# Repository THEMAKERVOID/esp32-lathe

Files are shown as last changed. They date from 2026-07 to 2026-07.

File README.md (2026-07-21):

# TheMakerVoid ELS — ESP32-S3 Electronic Lead Screw



An open-source **Electronic Lead Screw (ELS)** controller for manual lathes, built around the ESP32-S3 and a 320×240 ILI9341 TFT touchscreen. Synchronizes a servo/stepper motor with spindle rotation to automate feed and thread cutting operations.

> 🍺 **This project is free and open source.** If it's useful to you, consider [buying me a beer](https://buymeacoffee.com/themakervoid) — it helps keep the open-source hardware coming. Thank you!

---

## Features

- **4 operating modes** — Feed, Thread, Divider, and Configuration
- **Metric & Imperial (UTS) threads** — 16 metric pitches (0.20–4.00 mm) and 21 imperial pitches (8–56 TPI), selectable from the Thread Unit Switch screen
- **5 feed rates** — 0.07, 0.10, 0.13, 0.18, 0.25 mm/rev
- **Angular divider** — real-time angle readout from encoder
- **Dual input** — XPT2046 resistive touchscreen (debounced) and 4 physical buttons
- **Dark mode UI** — Figma-designed dark interface with Orbitron bitmap fonts
- **EEPROM persistence** — motor direction, lead screw pitch, and dark mode saved across power cycles
- **Dual-core architecture** — UI on Core0, servo synchronization on Core1 (FreeRTOS)
- **Bresenham pulse algorithm** — precise stepper pulse generation without floating-point drift

---

## Hardware

| Component | Details |
|---|---|
| Microcontroller | ESP32-S3 DevKit C-1 |
| Display | ILI9341 TFT 320×240, landscape |
| Encoder | Quadrature rotary encoder, 1440 pulses/rev |
| Servo/Stepper driver | [Lichuan AC servo driver (PUL/DIR interface)](https://s.click.aliexpress.com/e/_c3kWTQaX) |
| Touchscreen | XPT2046 resistive controller (on the ILI9341 module) |
| Input | XPT2046 touchscreen + 4 physical buttons: UP, DOWN, SELECT, BACK |

### Where to Buy

| Component | Link |
| --- | --- |
| AC Servo motor + driver | [AliExpress](https://s.click.aliexpress.com/e/_c3kWTQaX) |

**Recommended model: 1,000 W** — select the "1KW 4Nm 17b incremt" option (model **LCMT-10SLC17NB-80M04025B**): 4 Nm torque, 2500 RPM, 80 mm mounting flange (same specs as the unit used in this project).

*Affiliate link — as an AliExpress affiliate I may earn a commission at no extra cost to you.*

### Pin Map

| Function | GPIO |
|---|---|
| TFT CS / DC / RST | 10 / 11 / 12 |
| TFT SCK / MOSI / MISO | 15 / 13 / 14 |
| Touch CS / IRQ | 16 / 255 (IRQ unused) |
| Encoder A / B | 20 / 21 |
| Stepper PUL / DIR | 8 / 9 |
| BTN UP / DOWN / SELECT / BACK | 4 / 5 / 6 / 7 |
| Brake (reserved) | 3 |
| Encoder Z index (reserved) | 2 |

---

## UI Screens

| Screen | Description |
|---|---|
| Splash | Logo + boot animation |
| Main Menu | Mode selection + live RPM |
| Feed Select | Feed rate selection grid |
| Feed Mode | Active feed display + live RPM |
| Thread Unit Switch | Select Metric (mm) or Imperial (TPI) |
| Thread Select | Paginated pitch grid |
| Thread Mode | Active thread display + live RPM |
| Divider | Real-time angular position |
| Menu Overlay | Navigation hub |
| Config — Direction | CW / CCW motor direction |
| Config — Lead Screw Pitch | 1–10 mm digit selector |
| Interface | Dark mode toggle |
| Info | Firmware version and credits |

---

## Software Setup

### Requirements

- [Arduino IDE 2.x](https://www.arduino.cc/en/software)
- ESP32-S3 board package (via Boards Manager: `esp32` by Espressif)
- Libraries (via Library Manager):
  - Adafruit GFX Library
  - Adafruit ILI9341
  - XPT2046_Touchscreen
  - EEPROM (included with ESP32 core)

### Build & Flash

1. Clone or download this repository
2. Open `esp32-lathe/esp32-lathe.ino` in Arduino IDE 2.x
3. Select board: **ESP32S3 Dev Module**
4. Flash partition scheme: **Huge APP (3MB No OTA/1MB SPIFFS)** (recommended for PROGMEM bitmaps)
5. Upload

> **Note:** VS Code IntelliSense may show false errors for ESP32 headers. Arduino IDE 2.x compiles correctly.

---

## Project Structure

```
esp32-lathe/
├── esp32-lathe.ino       # Main sketch
├── bitmaps/              # PROGMEM RGB565 bitmap headers
│   ├── logo_splash.h
│   ├── bg_main.h
│   ├── btn_menu.h
│   ├── btn_back.h
│   ├── btn_ok.h
│   ├── btn_reload.h
│   ├── btn_stepper.h
│   ├── solid.h
│   └── btn_slider.h
├── Fonts/                # Orbitron & Montserrat bitmap font headers
│   ├── Orbitron_Medium8pt7b.h
│   ├── Orbitron_Medium12pt7b.h
│   ├── Orbitron_Medium18pt7b.h
│   ├── Orbitron_Medium24pt7b.h
│   └── Montserrat_Light6pt7b.h
└── Resources/            # Manuals, BOM, and 3D models (see Documentation)
    ├── User_Manual.pdf        # User manual (English)
    ├── Manual_Usuario.pdf     # User manual (Spanish)
    ├── ELS_Componentes.pdf    # Bill of materials / component list
    ├── Schematic.pdf          # Circuit schematic
    └── Components/            # 3D models of the mechanical parts (STEP / STL)
        ├── Base.STEP
        ├── Axis.STEP
        ├── Support.STEP
        ├── Encoder support.STEP
        ├── Main Pulley 50 Theet HTD5.STEP
        ├── Lathe Pulley 50 theet.STEP
        └── Frontal Caja Elecronica.STL
```

---

## How It Works

The encoder mounted on the lathe spindle generates quadrature pulses (1440 p/rev). Core1 runs a high-priority FreeRTOS task that reads the encoder count and computes stepper pulses using a **Bresenham integer accumulator**:

```
accumulator += |encoderDelta| × (desiredPitch × 100)
pulsesToSend  = accumulator / (leadScrewPitch × 100)
accumulator  %= (leadScrewPitch × 100)
```

This produces exact pulse ratios without floating-point error accumulation, enabling accurate thread cutting and feed synchronization.

---

## Documentation

Full user manuals and the component list are available in the [`esp32-lathe/Resources/`](esp32-lathe/Resources/) folder:

| Document | Language | Description |
|---|---|---|
| [User_Manual.pdf](esp32-lathe/Resources/User_Manual.pdf) | English | Complete user manual — operation, modes, and configuration |
| [Manual_Usuario.pdf](esp32-lathe/Resources/Manual_Usuario.pdf) | Español | Manual de usuario completo — funcionamiento, modos y configuración |
| [ELS_Componentes.pdf](esp32-lathe/Resources/ELS_Componentes.pdf) | Español | Bill of materials with links to the referenced parts / lista de componentes con enlaces a los referidos |
| [Schematic.pdf](esp32-lathe/Resources/Schematic.pdf) | — | Circuit schematic / esquema del circuito |

### 3D Models (mechanical parts)

3D models of the custom mechanical parts are in [`esp32-lathe/Resources/Components/`](esp32-lathe/Resources/Components/). STEP files are neutral CAD format (editable in any CAD tool); the STL is print-ready and previews directly on GitHub.

| Part | Format |
|---|---|
| [Base](esp32-lathe/Resources/Components/Base.STEP) | STEP |
| [Axis](esp32-lathe/Resources/Components/Axis.STEP) | STEP |
| [Support](esp32-lathe/Resources/Components/Support.STEP) | STEP |
| [Encoder support](esp32-lathe/Resources/Components/Encoder%20support.STEP) | STEP |
| [Main Pulley 50T HTD5](esp32-lathe/Resources/Components/Main%20Pulley%2050%20Theet%20HTD5.STEP) | STEP |
| [Lathe Pulley 50T](esp32-lathe/Resources/Components/Lathe%20Pulley%2050%20theet.STEP) | STEP |
| [Electronics box front](esp32-lathe/Resources/Components/Frontal%20Caja%20Elecronica.STL) | STL (3D-printable) |

---

## License

This project is open-source. See [LICENSE](LICENSE) for details.

---

## Credits

**TheMakerVoid** — [www.themakervoid.com](https://www.themakervoid.com)

Contributions, issues, and pull requests are welcome.

If this project helps you, support it with a beer 🍺 → [buymeacoffee.com/themakervoid](https://buymeacoffee.com/themakervoid)

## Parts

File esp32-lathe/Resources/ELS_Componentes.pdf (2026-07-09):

# Lista de Componentes — Proyecto ELS

Total de referencias: 11 · Ordenado alfabéticamente

Componente | Descripción | Cantidad | Enlace
Acoplador flexible de eje (Beam Coupling) | Acoplador de tipo helicoidal en aluminio negro, para transmisión de movimiento entre ejes con compensación de desalineación. | 1 unidad | AliExpress (https://s.click.aliexpress.com/e/_c445kgMx)
Conectores hembra para PCB (Pin Headers 2.54mm) | Tiras de conectores hembra de paso 2.54mm en negro. | 2×22 pines, 1×14 pines, 1×4 pines | AliExpress (https://s.click.aliexpress.com/e/_c41DaZ35)
Correa dentada HTD 5M 535mm | Correa sincrónica cerrada HTD-535-5M, paso 5mm, ancho 10mm. Para transmisión por polea dentada sin deslizamiento. | 1 unidad | AliExpress (https://s.click.aliexpress.com/e/_c3nUDYUb)
Display TFT 2.8" con pantalla táctil (SPI) | Módulo display TFT 2.8 pulgadas con táctil resistivo, interfaz SPI, controlador ILI9341. Compatible con Arduino/STM32. | 1 unidad | AliExpress (https://s.click.aliexpress.com/e/_c4Pz2QJD)
Encoder rotativo incremental 360 PPR | Encoder incremental industrial modelo C3856G5, 360 pulsos/revolución, alimentación 5-24V DC, salida en cuadratura. | 1 unidad | AliExpress (https://s.click.aliexpress.com/e/_c3sC9O8x)
ESP32-S3 DevKit (antena integrada) | Placa de desarrollo ESP32-S3 con antena onboard, doble USB-C, LED RGB, pines de expansión de 2.54mm. WiFi + Bluetooth 5.0. | 1 unidad | AliExpress (https://s.click.aliexpress.com/e/_c3dUvFUJ)
Fuente de alimentación Mean Well RS-15-5 | Fuente conmutada Mean Well serie RS, salida 5V DC, 15W. Entrada universal 85-264V AC. Formato compacto para carril DIN o montaje en panel. | 1 unidad | AliExpress (https://s.click.aliexpress.com/e/_c3cmoB51)
Imán de neodimio disco 20×5mm | Imán permanente de neodimio N35 en formato disco, 20mm diámetro × 5mm grosor. Alta fuerza de atracción. | 2 unidades | AliExpress (https://s.click.aliexpress.com/e/_c3nCReEB)
Módulo reductor DC-DC LM2596 (Buck Converter) | Convertidor reductor DC-DC basado en LM2596, tensión de salida ajustable. Se configura a 3.3V para alimentar el display TFT. | 1 unidad | AliExpress (https://s.click.aliexpress.com/e/_c3ljCbJd)
Prensaestopas PG11 negro | Prensaestopas de nylon negro PG11, para cables de 5-10mm de diámetro. Estanqueidad IP68. | 3 unidades | AliExpress (https://s.click.aliexpress.com/e/_c3gcngld)
Pulsador momentáneo rectangular iluminado 16mm | Pulsador momentáneo NO con cabeza rectangular iluminada, montaje en panel 16mm. | 2× blanco, 1× rojo, 1× verde | AliExpress (https://s.click.aliexpress.com/e/_c4p01EM7)

Generado: 28 de junio de 2026

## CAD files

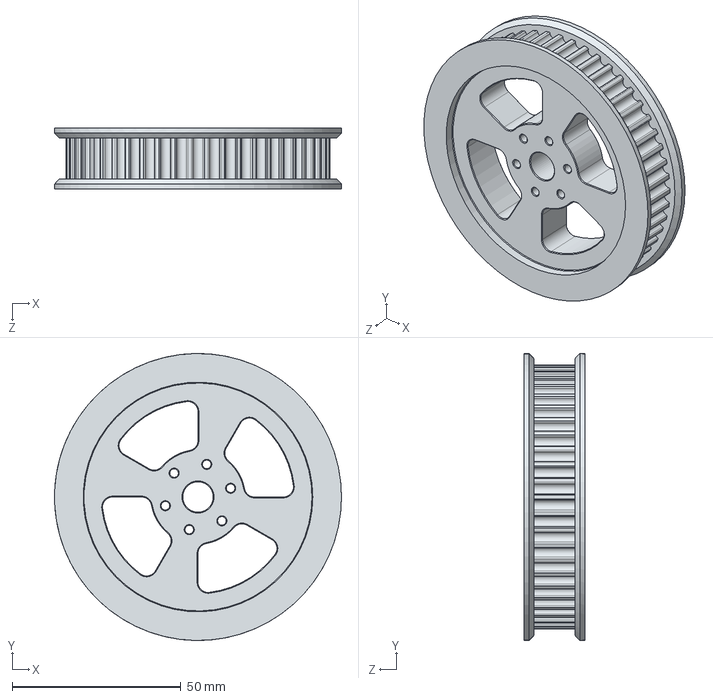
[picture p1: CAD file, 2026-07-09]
esp32-lathe/Resources/Components/Main Pulley 50 Theet HTD5.STEP
85.0 x 85.0 x 18.0 mm

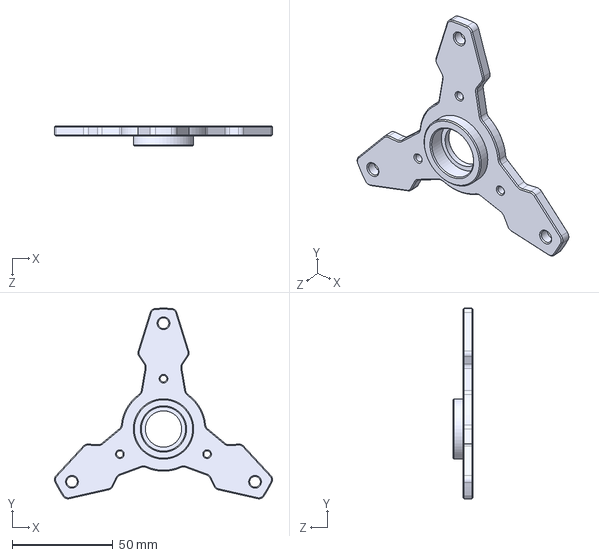
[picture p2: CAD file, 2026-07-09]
esp32-lathe/Resources/Components/Support.STEP
108.3 x 94.7 x 10.0 mm

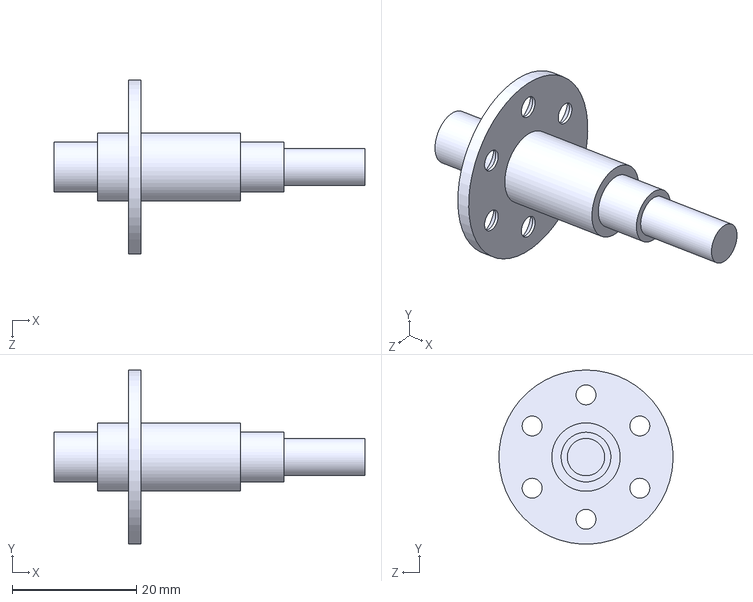
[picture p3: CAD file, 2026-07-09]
esp32-lathe/Resources/Components/Axis.STEP
50.0 x 28.0 x 28.0 mm

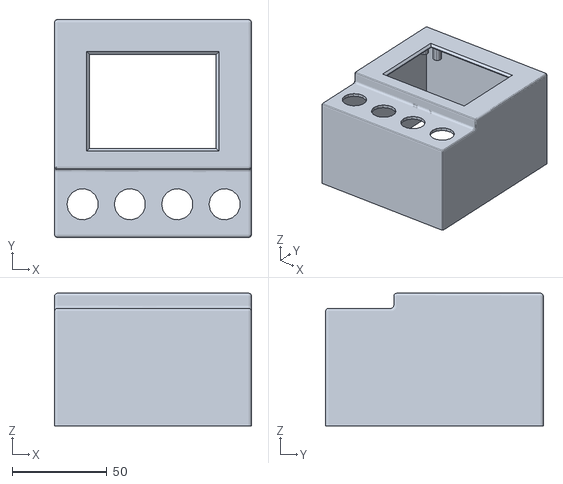
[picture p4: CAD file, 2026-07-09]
esp32-lathe/Resources/Components/Frontal Caja Elecronica.STL
104.0 x 115.0 x 70.0

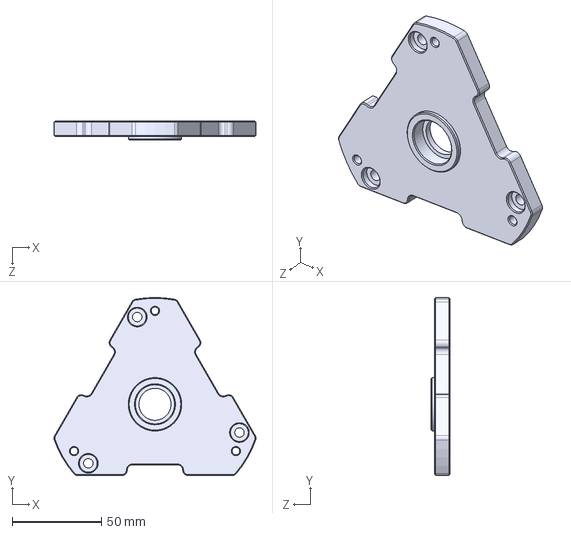
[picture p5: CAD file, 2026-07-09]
esp32-lathe/Resources/Components/Base.STEP
113.4 x 100.0 x 10.5 mm

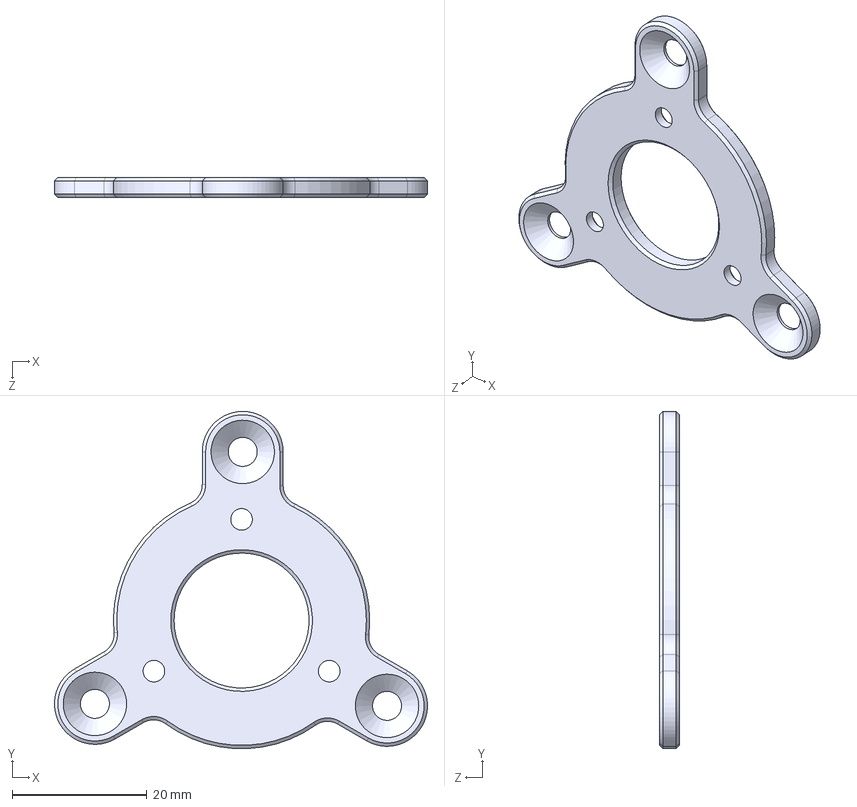
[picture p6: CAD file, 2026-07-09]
esp32-lathe/Resources/Components/Encoder support.STEP
55.3 x 50.0 x 3.00 mm

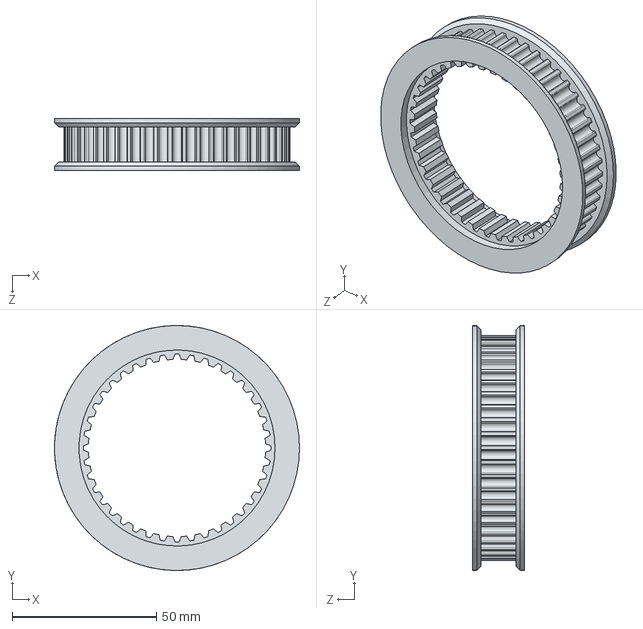
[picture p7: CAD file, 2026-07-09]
esp32-lathe/Resources/Components/Lathe Pulley 50 theet.STEP
85.0 x 85.0 x 18.0 mm

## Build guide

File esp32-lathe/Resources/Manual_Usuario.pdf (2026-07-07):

# TheMakerVoid ELS v1.0

### Avance Electrónico de Husillo para Tornos — Manual de Usuario

ESP32-S3 • Pantalla táctil ILI9341 320×240 • Servo Lichuan A6 • Encoder de cabezal 1440 p/rev

## 1. Introducción

El TheMakerVoid ELS (Electronic Lead Screw / Avance Electrónico de Husillo) es un controlador que acopla electrónicamente el cabezal del torno con el motor que mueve el carro. En lugar de cambiar los engranajes mecánicos, el controlador lee el giro del cabezal mediante un encoder rotativo y ordena a un servo mover el carro en una relación perfectamente sincronizada. Esto permite realizar avance automático y roscado — tanto métrico como imperial — y usar el cabezal como plato divisor / cabezal divisor, todo seleccionado desde un menú táctil.

La unidad se maneja con la pantalla táctil resistiva o con cuatro botones físicos (UP, DOWN, SELECT, BACK). Ambos métodos de entrada están siempre activos y hacen exactamente lo mismo.

A quién va dirigido: torneros y aficionados que instalan un ELS en un torno manual. Se asume familiaridad básica con avances, paso de rosca y TPI.

### Contenido

2. Seguridad • 3. Descripción del hardware • 4. Controles • 5. Encendido • 6. Menú principal • 7. Modo Avance • 8. Modo Rosca • 9. Modo Divisor • 10. Menú de ajustes • 11. Configuración • 12. Interfaz e Info • 13. Tablas de
referencia • 14. Resolución de problemas

## 2. Seguridad

Léalo antes de usar. Un ELS ordena el movimiento del carro automáticamente siempre que el cabezal gira en modo Avance o Rosca. Un descuido puede hacer que el carro choque contra el plato o atrape sus manos.

- Sepa siempre en qué dirección se desplazará el carro antes de engranar. Verifique el ajuste de dirección CW/CCW (Sección 11.1) para su máquina.
- Mantenga el control BACK al alcance. Pulsar BACK desde el modo Avance o Rosca detiene el motor de inmediato y vuelve al Menú principal.
- Confirme que el paso del husillo patrón configurado (Sección 11.2) coincide con el husillo real de su torno. Un valor incorrecto produce una relación de avance/rosca incorrecta.
- Haga una pasada de prueba lejos de la pieza la primera vez que use un avance o un paso de rosca nuevo.
- El motor solo se mueve mientras el cabezal se mueve. Detener el cabezal detiene el carro.

## 3. Descripción del hardware

Componente | Especificación
Microcontrolador | ESP32-S3 DevKit C-1 (doble núcleo)
Pantalla | TFT ILI9341, 320×240 px, horizontal, táctil resistiva (XPT2046)
Encoder de cabezal | Encoder rotativo en cuadratura, 1440 pulsos por revolución
Driver del motor | Servo Lichuan A6, interfaz PUL/DIR (paso y dirección)
Entrada física | 4 botones: UP, DOWN, SELECT, BACK
Memoria persistente | EEPROM — guarda dirección, paso del husillo y modo oscuro

Internamente el controlador usa los dos núcleos del ESP32: un
núcleo gestiona la interfaz y la pantalla, mientras un segundo núcleo dedicado de alta prioridad no hace otra cosa que leer el encoder y generar los pulsos del motor en tiempo real. Esta separación mantiene el movimiento preciso y sin tirones incluso mientras usted navega por los menús.

## 4. Controles

### 4.1 Botones físicos

Botón | Función general
UP | Subir selección / elemento anterior / incrementar un dígito
DOWN | Bajar selección / elemento siguiente / decrementar un dígito
SELECT | Confirmar / entrar en la opción resaltada / avanzar
BACK | Retroceder un nivel. Desde el Menú principal abre la superposición de Ajustes; desde el modo Avance/Rosca detiene el motor y vuelve al Menú principal.

### 4.2 Pantalla táctil

Cada botón en pantalla, elemento de lista y flecha se puede tocar directamente. La pantalla reconoce un toque cada vez e ignora repeticiones durante una fracción de segundo para evitar dobles toques accidentales. Iconos en pantalla habituales:

Icono | Significado
Menú (arriba dcha.) | Abre la superposición de Ajustes (Configuración / Interfaz / Info).
Atrás (abajo dcha.) | Vuelve a la pantalla anterior / cancela.
OK (abajo dcha., a la izq. de Atrás) | Confirma la selección actual o guarda el ajuste.
Recargar (pantalla Divisor) | Pone a cero la lectura del ángulo.

Flechas ◀ / ▶ | Página anterior / siguiente en listas largas (selección de rosca).
Incrementadores ▲/▼ | Incrementar / decrementar el dígito seleccionado (paso del husillo).

## 5. Encendido

Al aplicar la alimentación, el controlador muestra una pantalla de bienvenida con el logotipo de TheMakerVoid durante unos 5 segundos. Puede saltarla al instante tocando la pantalla o pulsando cualquier botón. Tras la bienvenida aparece el Menú principal.

En el primer encendido el controlador inicializa sus ajustes guardados con valores seguros por defecto (dirección = CW, paso del husillo = 3 mm, modo oscuro = activado). En cada arranque posterior restaura lo último que usted guardó.

## 6. Menú principal

El Menú principal es la pantalla de inicio. Muestra los tres modos de operación a la derecha y las RPM del cabezal en vivo abajo a la izquierda, que se actualizan continuamente mientras el cabezal gira (de modo que puede usarlo como tacómetro en cualquier momento).

Opción | Lleva a
FEED (Avance) | Selección de avance → avance automático (Sección 7)
THREAD (Rosca) | Elección Métrico/Imperial → selección de paso → roscado (Sección 8)
DIVIDER (Divisor) | Lectura de ángulo / indexado del cabezal en vivo (Sección 9)
Navegación: use | UP / DOWN | para resaltar un modo y | SELECT | para
entrar, o simplemente tóquelo. Pulse | BACK | (o toque el icono
Menú) para abrir la superposición de Ajustes.

## 7. Modo Avance (avance automático)

El modo Avance desplaza el carro una distancia fija por revolución del cabezal — el equivalente electrónico de engranar el avance con los engranajes de cambio.

### 7.1 Seleccionar un avance

Desde el Menú principal elija FEED. Aparece una cuadrícula con los avances disponibles (en mm por revolución). Los cinco avances son:

0.07 • 0.10 • 0.13 • 0.18 • 0.25 mm/rev

Resalte un avance con | UP / DOWN | (o tóquelo), luego pulse | SELECT
/ toque OK para engranar.

### 7.2 Durante el avance

La pantalla del modo Avance muestra el valor de avance activo y las RPM en vivo. En cuanto el cabezal gira, el controlador mueve el carro al avance seleccionado. Detener el cabezal detiene el carro.

Para detener el avance, pulse | BACK | o toque Atrás. Esto
desactiva el motor de inmediato y le devuelve al Menú principal.

La dirección del avance sigue la dirección del motor configurada (Sección 11.1) combinada con el sentido de giro del cabezal.

## 8. Modo Rosca (roscado)

El modo Rosca sincroniza el carro para cortar una rosca de un paso elegido. Admite pasos métricos y roscas imperiales (UTS) especificadas en TPI.

### 8.1 Elegir el estándar de rosca

Desde el Menú principal elija THREAD. La pantalla Thread Unit Switch le pregunta qué estándar desea:

Opción Significado

METRIC | Paso especificado en milímetros (mm).
UTS | Roscas imperiales / unificadas especificadas en hilos por pulgada (TPI).
Alterne con | UP / DOWN | (o toque), luego confirme con | SELECT | /
OK.

### 8.2 Seleccionar el paso

Aparece una cuadrícula paginada de pasos (seis por página). Use las flechas ◀/▶ abajo a la izquierda — o siga pulsando UP / DOWN , que recorre las páginas automáticamente y da la vuelta al llegar al final — para encontrar su paso. El encabezado muestra las unidades en uso, (mm) o (tpi).

- Métrico: 16 pasos de 0.20 mm a 4.00 mm.
- Imperial (UTS): 21 valores de 8 TPI a 56 TPI.

(Listas completas en la Sección 13.) Resalte el paso y pulse SELECT / toque OK para engranar.

### 8.3 Durante el corte

La pantalla del modo Rosca muestra el paso activo (en mm) o el valor TPI más las RPM en vivo, y el carro sigue al cabezal en la relación exacta de esa rosca. Igual que con el avance, pulse BACK / toque Atrás para detener el motor y volver al Menú principal.

Importante: el controlador mantiene la relación de paso correcta, pero el roscado sigue requiriendo técnica correcta — velocidad de cabezal adecuada, retirar la herramienta al final de cada pasada y reengranar en el mismo punto. El ELS mantiene el movimiento del carro bloqueado al cabezal; no automatiza la penetración de la herramienta ni el tope de rosca.

## 9. Modo Divisor (indexado)

El modo Divisor convierte el encoder del cabezal en una lectura de posición angular precisa, útil para trabajos de indexado como círculos de agujeros, caras planas, engranajes o graduaciones.

- La pantalla muestra el ángulo actual del cabezal en grados (0–360°), actualizado en tiempo real al girar el cabezal a mano.
- Toque el icono Recargar (o pulse SELECT ) para poner a cero el ángulo en la posición actual — fije su referencia y gire hasta el ángulo que necesite.
- Pulse | BACK | / toque Atrás para volver al Menú principal.

Como el encoder tiene 1440 pulsos por revolución, la lectura resuelve hasta un cuarto de grado.

## 10. Menú de ajustes (superposición)

Desde el Menú principal, pulse | BACK | o toque el icono Menú
(arriba a la derecha en casi todas las pantallas) para abrir la superposición de Ajustes. Ofrece tres elementos:
Elemento | Finalidad
CONFIGURATION | Ajustar la dirección del motor y el paso del husillo (Sección 11).
INTERFACE | Activar/desactivar el modo oscuro (Sección 12.1).
INFO | Versión del firmware y créditos (Sección 12.2).
Navegue con | UP / DOWN | + | SELECT , o toque. | BACK | / Atrás vuelve
al punto de partida.

## 11. Configuración

Estos dos ajustes definen cómo calcula el controlador cada relación de avance y rosca. Se guardan permanentemente en la EEPROM y sobreviven a los ciclos de apagado. Configúrelos una vez para su máquina.

### 11.1 Dirección (CW / CCW)

Selecciona el sentido de giro del motor que corresponde al avance del carro hacia delante en su torno.

- Toque CW (horario) o CCW (antihorario), o alterne con
UP / DOWN .
- Confirme con OK / | SELECT | para guardar; el valor se
escribe en memoria y se aplica al motor de inmediato.
- Atrás cancela sin guardar.

Si el carro se mueve en sentido contrario al engranar Avance o Rosca, vuelva aquí y cambie este ajuste.

### 11.2 Paso del husillo patrón

Indica al controlador el paso del husillo patrón de su torno, en milímetros. Es la referencia sobre la que se basa todo el cálculo de relaciones, así que debe coincidir con su máquina real.

- El valor se introduce con dos dígitos (decenas y unidades), rango 1–10 mm.
- Toque una casilla de dígito para seleccionarla, luego use
las flechas ▲/▼ en pantalla — o | UP / DOWN | — para
cambiar ese dígito (los dígitos giran 0…9).
- Pulse OK / | SELECT | para pasar del dígito de las decenas
al de las unidades; pulsarlo de nuevo en las unidades guarda el valor y vuelve al menú de Configuración.
- Atrás cancela.

## 12. Interfaz e Info

### 12.1 Interfaz — Modo oscuro

La pantalla Interfaz tiene un único conmutador DARK MODE (modo oscuro). Toque el deslizador (o pulse SELECT ) para alternar entre el tema oscuro y un tema invertido (claro); el cambio se muestra al instante. El ajuste se guarda al salir de la pantalla con Atrás.

### 12.2 Info

La pantalla Info lista la identificación del firmware y el hardware, y los créditos del proyecto:

- TheMakerVoid ELS v1.0
- ESP32-S3 DevKit C-1 • TFT ILI9341 320×240
- Servo Lichuan A6 • Encoder 1440 p/rev
- Proyecto de código abierto / dominio público — libre de usar como desee.

- Enlaces de proyecto y donaciones a www.themakervoid.com.

## 13. Tablas de referencia

### 13.1 Avances (mm / revolución)

# | 1 | 2 | 3 | 4 | 5

mm/rev | 0.07 | 0.10 | 0.13 | 0.18 | 0.25

### 13.2 Pasos de rosca métrica (mm) — 16 valores

0.20 | 0.30 | 0.40 | 0.50 | 0.60 | 0.70 | 0.80 | 1.00
1.25 | 1.50 | 1.75 | 2.00 | 2.50 | 3.00 | 3.50 | 4.00

### 13.3 Roscas imperiales (UTS) — TPI — 21 valores

8 | 9 | 9.5 | 10 | 11 | 12 | 14
16 | 18 | 19 | 20 | 22 | 24 | 28
32 | 36 | 38 | 40 | 44 | 48 | 56

### 13.4 Ajustes por defecto (primer encendido)

Ajuste | Por defecto
Dirección del motor | CW (horario)
Paso del husillo patrón | 3 mm
Modo oscuro | Activado

## 14. Resolución de problemas

Síntoma | Causa probable / solución
El carro se mueve en sentido contrario | Invierta el ajuste de Dirección (Sección 11.1).
El paso de avance/rosca está mal por un factor constante | Compruebe que el valor de Paso del husillo (Sección 11.2) coincide con el husillo patrón de su máquina.
Las RPM marcan 0 mientras el cabezal gira | Problema de cableado / acoplamiento del encoder; confirme que el encoder gira con el cabezal.
El motor no se mueve en modo Avance/Rosca | Asegúrese de haber confirmado la selección con OK/SELECT (el modo debe estar engranado, no solo seleccionado); verifique la alimentación del driver y el cableado PUL/DIR.
El táctil está desplazado o no responde | La pantalla táctil necesita calibración específica del panel; recalíbrela en el firmware.
Los ajustes se reinician tras apagar | Debe pulsar OK/SELECT para guardar un ajuste; salir con Atrás descarta los cambios de Dirección/Paso.
El carro sigue moviéndose cuando quiere parar | Pulse BACK desde el modo Avance/Rosca — esto desactiva el motor. Detener el cabezal también detiene el movimiento.

TheMakerVoid ELS v1.0 — Manual de Usuario. Proyecto de código abierto / dominio público. www.themakervoid.com

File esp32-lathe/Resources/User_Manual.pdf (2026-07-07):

# TheMakerVoid ELS v1.0

### Electronic Lead Screw for Metal Lathes — User Manual

ESP32-S3 • ILI9341 320×240 Touchscreen • Lichuan A6 Servo • 1440 p/rev Spindle Encoder

## 1. Introduction

The TheMakerVoid ELS (Electronic Lead Screw) is a controller that electronically couples your lathe's spindle to the carriage drive motor. Instead of swapping physical change gears, the controller reads the spindle rotation through a rotary encoder and commands a servo (or stepper) motor to move the carriage at a precisely synchronized ratio. This lets you perform automatic feeding and thread cutting — in both metric and imperial — and use the spindle as an indexing / dividing head, all selected from a touchscreen menu.

The unit is operated either by the resistive touchscreen or by four physical buttons (UP, DOWN, SELECT, BACK). Both input methods are always active and do exactly the same things.

Who this is for: machinists and hobbyists fitting an ELS to a manual lathe. Basic familiarity with lathe feed rates, thread pitch, and TPI is assumed.

### Contents

2. Safety • 3. Hardware Overview • 4. Controls • 5. Powering On • 6. Main Menu • 7. Feed Mode • 8. Thread Mode • 9. Divider Mode • 10. Settings Menu • 11. Configuration • 12. Interface & Info • 13. Reference Tables • 14. Troubleshooting

## 2. Safety

Read before use. An ELS commands carriage motion automatically whenever the spindle turns in Feed or Thread mode. Carelessness can crash the carriage into the chuck or your hands.

- Always know which direction the carriage will travel before engaging. Verify the CW/CCW direction setting (Section 11.1) for your machine.
- Keep the BACK control within reach. Pressing BACK from Feed or Thread mode immediately stops the motor and returns to the Main Menu.
- Confirm the configured lead screw pitch (Section 11.2) matches your lathe's actual lead screw. A wrong value produces a wrong feed/thread ratio.
- Make a trial pass clear of the workpiece the first time you use a new feed rate or thread pitch.
- The motor only moves while the spindle moves. Stopping the spindle stops the carriage.

## 3. Hardware Overview

Component | Specification
Microcontroller | ESP32-S3 DevKit C-1 (dual-core)
Display | ILI9341 TFT, 320×240 px, landscape, resistive touch (XPT2046)
Spindle encoder | Quadrature rotary encoder, 1440 pulses per revolution
Motor driver | Lichuan A6 servo drive, PUL/DIR (step & direction) interface
Physical input | 4 buttons: UP, DOWN, SELECT, BACK
Persistent memory | EEPROM — stores direction, lead screw pitch, and dark mode

Internally the controller uses both ESP32 cores: one core drives
the user interface and screen, while a second dedicated high-priority core does nothing but read the encoder and generate
motor pulses in real time. This separation keeps motion accurate and jitter-free even while you navigate menus.

## 4. Controls

### 4.1 Physical Buttons

Button General function

UP | Move selection up / previous item / increment a digit
DOWN | Move selection down / next item / decrement a digit
SELECT | Confirm / enter the highlighted option / advance
BACK | Go back one level. From the Main Menu it opens the Settings overlay; from Feed/Thread mode it stops the motor and returns to the Main Menu.

### 4.2 Touchscreen

Every on-screen button, list item, and arrow can be tapped directly. The screen recognizes one touch at a time and ignores repeats for a fraction of a second to prevent accidental double-taps. Common on-screen icons:

Icon | Meaning
Menu (top-right) | Opens the Settings overlay (Configuration / Interface / Info).
Back (bottom-right) | Returns to the previous screen / cancels.
OK (bottom-right, left of Back) | Confirms the current selection or saves the setting.
Reload (Divider screen) | Resets the angle reading to zero.
◀ / ▶ carets | Previous / next page in long lists (thread selection).
Stepper ▲/▼ | Increment / decrement the selected digit (lead screw pitch).

## 5. Powering On

When power is applied, the controller shows a splash screen with the TheMakerVoid logo for about 5 seconds. You can skip it immediately by touching the screen or pressing any button. After the splash, the Main Menu appears.

On first power-up the controller initializes its saved settings to safe defaults (direction = CW, lead screw pitch = 3 mm, dark mode = on). On every subsequent boot it restores whatever you last saved.

## 6. Main Menu

The Main Menu is the home screen. It shows the three operating modes on the right and the live spindle RPM at the bottom-left, which updates continuously as the spindle turns (so you can use it as a tachometer at any time).

Option | Goes to
FEED | Feed-rate selection → automatic feeding (Section 7)
THREAD | Metric/Imperial choice → pitch selection → thread cutting (Section 8)
DIVIDER | Live spindle angle / indexing readout (Section 9)
Navigation: use | UP / DOWN | to highlight a mode and | SELECT | to
enter it, or simply tap it. Press | BACK | (or tap the Menu icon) to
open the Settings overlay.

## 7. Feed Mode (Automatic Feeding)

Feed Mode drives the carriage at a fixed distance per spindle revolution — the electronic equivalent of engaging the feed via change gears.

### 7.1 Selecting a feed rate

From the Main Menu choose FEED. A grid of available feed rates (in mm per revolution) appears. The five rates are:

0.07 • 0.10 • 0.13 • 0.18 • 0.25 mm/rev

Highlight a rate with | UP / DOWN | (or tap it), then press | SELECT | /
tap OK to engage.

### 7.2 While feeding

The Feed Mode screen shows the active feed value and the live RPM. As soon as the spindle turns, the controller moves the carriage at the selected rate. Stopping the spindle stops the carriage.

To stop feeding, press | BACK | or tap Back. This immediately
disables the motor and returns you to the Main Menu.

Feed direction follows the configured motor direction (Section 11.1) combined with the spindle's rotation direction.

## 8. Thread Mode (Thread Cutting)

Thread Mode synchronizes the carriage to cut a thread of a chosen pitch. It supports both metric pitches and imperial (UTS) threads specified in TPI.

### 8.1 Choosing the thread standard

From the Main Menu choose THREAD. The Thread Unit Switch screen asks which standard you want:

Option | Meaning
METRIC | Pitch specified in millimetres (mm).
UTS | Imperial / Unified threads specified in threads per inch (TPI).
Toggle with | UP / DOWN | (or tap), then confirm with | SELECT | / OK.

### 8.2 Selecting the pitch

A paginated grid of pitches appears (six per page). Use the ◀/▶ carets at the bottom-left — or keep pressing UP / DOWN , which scrolls across pages automatically and wraps around —

to find your pitch. The header shows the units in use, (mm) or
(tpi).
- Metric: 16 pitches from 0.20 mm to 4.00 mm.
- Imperial (UTS): 21 values from 8 TPI to 56 TPI.
(Full lists in Section 13.) Highlight the pitch and press | SELECT | /
tap OK to engage.

### 8.3 While cutting

The Thread Mode screen shows the active pitch (in mm) or TPI value plus the live RPM, and the carriage tracks the spindle at
the exact ratio for that thread. As with feeding, press | BACK | / tap
Back to stop the motor and return to the Main Menu.

Important: the controller maintains the correct lead ratio, but thread cutting still requires correct technique — appropriate spindle speed, retracting the tool at the end of each pass, and re-engaging at the same point. The ELS keeps carriage motion locked to the spindle; it does not automate tool infeed or thread-stop.

## 9. Divider Mode (Indexing)

Divider Mode turns the spindle encoder into a precise angular position readout, useful for indexing work such as bolt-hole circles, flats, gears, or graduations.

- The screen shows the current spindle angle in degrees (0–360°), updated in real time as you rotate the spindle by hand.
- Tap the Reload icon (or press SELECT ) to zero the angle at the current position — set your reference, then rotate to the angle you need.
- Press | BACK | / tap Back to return to the Main Menu.

Because the encoder has 1440 pulses per revolution, the readout resolves to a quarter of a degree.

## 10. Settings Menu (Overlay)

From the Main Menu, press | BACK | or tap the Menu icon (top-
right of most screens) to open the Settings overlay. It offers three items:

Item | Purpose
CONFIGURATION | Set motor direction and lead screw pitch (Section 11).
INTERFACE | Toggle dark mode (Section 12.1).
INFO | Firmware version and credits (Section 12.2).
Navigate with | UP / DOWN | + | SELECT , or tap. | BACK | / Back returns to
where you came from.

## 11. Configuration

These two settings define how the controller calculates every feed and thread ratio. They are stored permanently in EEPROM and survive power cycles. Set them up once for your machine.

### 11.1 Direction (CW / CCW)

Selects the motor rotation direction that corresponds to forward carriage travel on your lathe.

- Tap CW or CCW (or toggle with | UP / DOWN ).
- Confirm with OK / | SELECT | to save; the value is written to
memory and applied to the motor immediately.
- Back cancels without saving.

If the carriage runs the wrong way when you engage Feed or Thread mode, return here and switch this setting.

### 11.2 Lead Screw Pitch

Tells the controller the pitch of your lathe's lead screw, in millimetres. This is the reference the ratio math is built on, so it must match your actual machine.

- The value is entered as two digits (tens and units), range 1–10 mm.
- Tap a digit box to select it, then use the on-screen ▲/▼
stepper arrows — or | UP / DOWN | — to change that digit
(digits wrap 0…9).

- Press OK / | SELECT | to advance from the tens digit to the
units digit; pressing it again on the units digit saves the value and returns to the Configuration menu.
- Back cancels.

## 12. Interface & Info

### 12.1 Interface — Dark Mode

The Interface screen has a single DARK MODE toggle. Tap the slider (or press SELECT ) to switch between the dark theme and an inverted (light) theme; the change is shown instantly. The setting is saved when you leave the screen with Back.

### 12.2 Info

The Info screen lists firmware and hardware identification and project credits:

- TheMakerVoid ELS v1.0
- ESP32-S3 DevKit C-1 • ILI9341 TFT 320×240
- Lichuan A6 Servo • Encoder 1440 p/rev
- An open-source / public-domain project — free to use as you wish.
- Project & donation links to www.themakervoid.com.

## 13. Reference Tables

### 13.1 Feed rates (mm / revolution)

# | 1 | 2 | 3 | 4 | 5

mm/rev | 0.07 | 0.10 | 0.13 | 0.18 | 0.25

### 13.2 Metric thread pitches (mm) — 16 values

0.20 | 0.30 | 0.40 | 0.50 | 0.60 | 0.70 | 0.80 | 1.00
1.25 | 1.50 | 1.75 | 2.00 | 2.50 | 3.00 | 3.50 | 4.00

### 13.3 Imperial (UTS) threads — TPI — 21 values

8 | 9 | 9.5 | 10 | 11 | 12 | 14
16 | 18 | 19 | 20 | 22 | 24 | 28
32 | 36 | 38 | 40 | 44 | 48 | 56

### 13.4 Default settings (first power-up)

Setting | Default
Motor direction | CW
Lead screw pitch | 3 mm
Dark mode | On

## 14. Troubleshooting

Symptom | Likely cause / remedy
Carriage moves the wrong way | Reverse the Direction setting (Section 11.1).
Feed/thread pitch is wrong by a constant factor | Check the Lead Screw Pitch value (Section 11.2) matches your machine's lead screw.
RPM reads 0 while spindle turns | Encoder wiring / coupling problem; confirm the encoder turns with the spindle.
Motor does not move in Feed/Thread mode | Make sure you confirmed the selection with OK/SELECT (the mode must be engaged, not just selected); verify motor driver power and PUL/DIR wiring.

Touch is offset or unresponsive | The touchscreen needs panel-specific calibration; have it recalibrated in firmware.
Settings reset after power cycle | You must press OK/SELECT to save a setting; leaving with Back discards Direction/Pitch changes.
Carriage keeps moving after you want to stop | Press BACK from Feed/Thread mode — this disables the motor. Stopping the spindle also stops motion.

TheMakerVoid ELS v1.0 — User Manual. Open-source / public-domain project. www.themakervoid.com

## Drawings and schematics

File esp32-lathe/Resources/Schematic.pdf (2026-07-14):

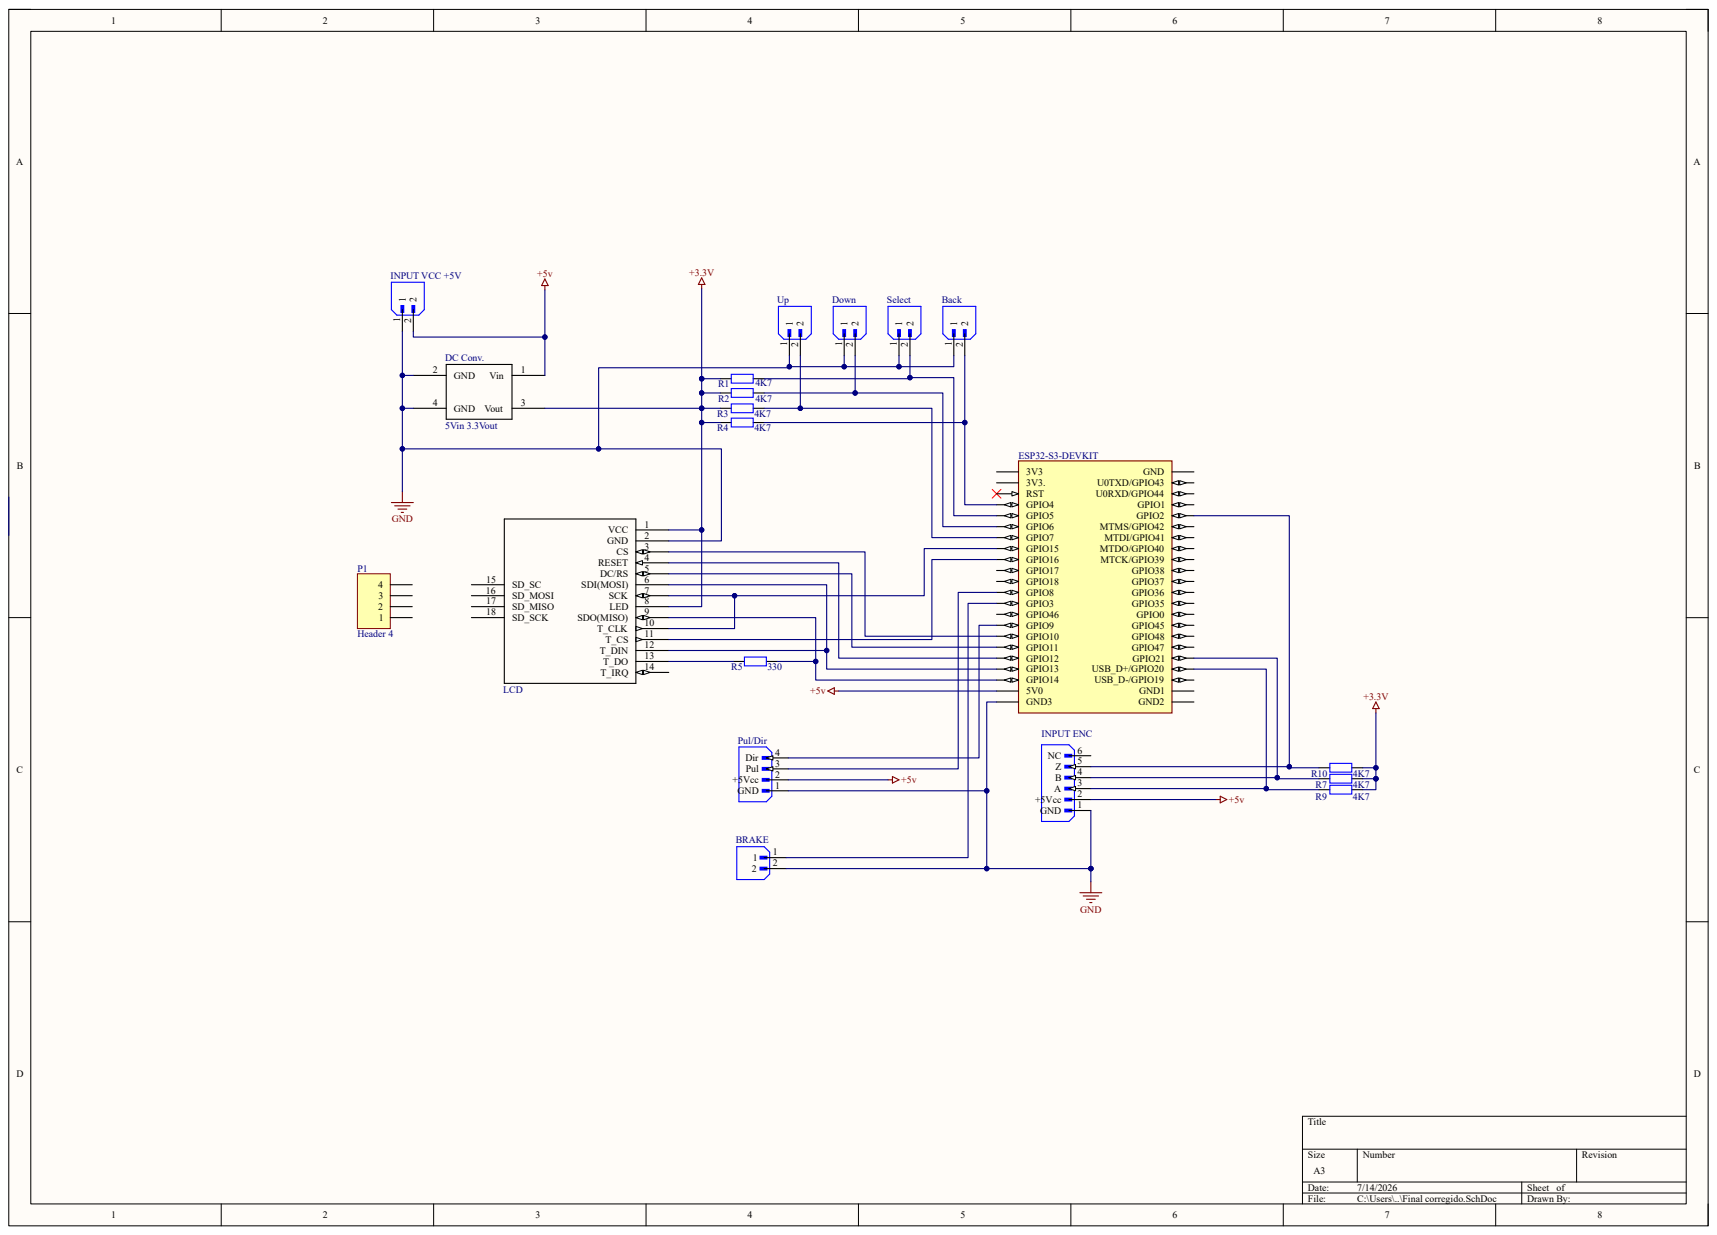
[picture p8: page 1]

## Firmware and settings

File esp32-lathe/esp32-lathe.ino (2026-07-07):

#include <SPI.h>
#include <Adafruit_GFX.h>
#include <Adafruit_ILI9341.h>
#include <rom/ets_sys.h>   // ets_delay_us() — delay without disabling interrupts (Core1)
#include <XPT2046_Touchscreen.h>
#include <EEPROM.h>
#include <math.h>
#include "bitmaps/logo_splash.h"
#include "bitmaps/bg_main.h"
#include "bitmaps/btn_menu.h"
#include "bitmaps/btn_back.h"
#include "bitmaps/btn_ok.h"
#include "bitmaps/btn_reload.h"
#include "bitmaps/btn_stepper.h"
#include "bitmaps/solid.h"
#include "bitmaps/btn_slider.h"
#include "Fonts/Orbitron_Medium8pt7b.h"
#include "Fonts/Orbitron_Medium12pt7b.h"
#include "Fonts/Orbitron_Medium18pt7b.h"
#include "Fonts/Orbitron_Medium24pt7b.h"
#include "Fonts/Montserrat_Light6pt7b.h"

#define TFT_CS 10
#define TFT_DC 11
#define TFT_RST 12
#define TFT_SCK 15
#define TFT_MOSI 13
#define TFT_MISO 14
#define TOUCH_CS 16
#define TOUCH_IRQ 255
#define BTN_UP 4
#define BTN_DOWN 5
#define BTN_SELECT 6
#define BTN_BACK 7
#define ENC_A 20
#define ENC_B 21
#define PUL_PIN 8
#define DIR_PIN 9
#define BRAKE_PIN 3  // GPIO for electromagnetic brake control
#define ENC_Z 2      // GPIO for encoder Z (index) signal - reserved

XPT2046_Touchscreen touch(TOUCH_CS, TOUCH_IRQ);

#define EEPROM_MAGIC_ADDR 0
#define EEPROM_DIRECTION_ADDR 1
#define EEPROM_LEADSCREW_ADDR 2
#define EEPROM_DARKMODE_ADDR 3
#define EEPROM_MAGIC_VALUE 0xAC  // Bumped to force re-init after adding darkMode

constexpr int QUAD = 1440;
constexpr float LEAD = 3.0f;
constexpr uint16_t UPDATE_RPM = 200;
constexpr uint16_t UPDATE_ANGLE = 50;
constexpr uint16_t DEBOUNCE_DELAY = 200;
constexpr int TS_MINX = 395;   // Touch calibration — adjust for your panel
constexpr int TS_MAXX = 3846;
constexpr int TS_MINY = 412;
constexpr int TS_MAXY = 3739;
constexpr uint16_t TOUCH_DEBOUNCE = 250;  // ms between touch events

const float avances[] = {0.07f, 0.10f, 0.13f, 0.18f, 0.25f};
const int NUM_AV = 5;
// Metric thread pitches (mm)
const float roscas[] = {0.20f, 0.30f, 0.40f, 0.50f, 0.60f, 0.70f, 0.80f, 1.00f,
                         1.25f, 1.50f, 1.75f, 2.00f, 2.50f, 3.00f, 3.50f, 4.00f};
const int NUM_ROS = 16;

// Imperial thread pitches — TPI values and their mm equivalents
const float tpi_vals[]        = {8, 9, 9.5f, 10, 11, 12, 14, 16, 18, 19,
                                  20, 22, 24, 28, 32, 36, 38, 40, 44, 48, 56};
const float roscas_imperial[] = {25.4f/8,  25.4f/9,  25.4f/9.5f, 25.4f/10, 25.4f/11,
                                  25.4f/12, 25.4f/14, 25.4f/16,   25.4f/18, 25.4f/19,
                                  25.4f/20, 25.4f/22, 25.4f/24,   25.4f/28, 25.4f/32,
                                  25.4f/36, 25.4f/38, 25.4f/40,   25.4f/44, 25.4f/48,
                                  25.4f/56};
const int NUM_ROS_IMP = 21;
constexpr int ROSCA_PAGE_SIZE = 6;  // items per page (2×3 grid)

// UI color palette (Figma Dark Mode)
constexpr uint16_t C_BG     = 0x18E4;  // #1F1F21 background (canvas)
constexpr uint16_t C_PANEL  = 0x18E4;  // #1F1F21 panel/card
constexpr uint16_t C_BTN    = 0x2966;  // #2A2D34 button OFF background
constexpr uint16_t C_MUTED  = 0x52AB;  // #55575D text OFF / inactive
constexpr uint16_t C_ACCENT = 0x5330;  // #556483 button ON / accent / border
constexpr uint16_t C_WHITE  = 0xFFFF;  // #FFFFFF text ON / borders

constexpr uint32_t SPLASH_DURATION = 5000;  // ms


enum class AppState : uint8_t {
  SPLASH,
  MAIN_MENU, AVANCE_MODE, AVANCE_SELECT, ROSCADO_MODE,
  ROSCA_SELECT, THREAD_UNIT_SWITCH, DIVISOR_MODE,
  CONFIG_MENU, CONFIG_DIRECTION, CONFIG_RATIO,
  MENU_OVERLAY, INFO_SCREEN, INTERFACE_SCREEN
};

enum class ButtonEvent : uint8_t { NONE, PRESSED };

struct Config {
  bool cwDirection;
  uint8_t leadScrewPitch;
  bool darkMode;
  Config() : cwDirection(true), leadScrewPitch(3), darkMode(true) {}
  void load() {
    if(EEPROM.read(EEPROM_MAGIC_ADDR) == EEPROM_MAGIC_VALUE) {
      cwDirection = EEPROM.read(EEPROM_DIRECTION_ADDR);
      leadScrewPitch = EEPROM.read(EEPROM_LEADSCREW_ADDR);
      if(leadScrewPitch < 1 || leadScrewPitch > 10) leadScrewPitch = 3;
      darkMode = EEPROM.read(EEPROM_DARKMODE_ADDR);
    } else {
      save();
    }
  }
  void save() {
    EEPROM.write(EEPROM_MAGIC_ADDR, EEPROM_MAGIC_VALUE);
    EEPROM.write(EEPROM_DIRECTION_ADDR, cwDirection);
    EEPROM.write(EEPROM_LEADSCREW_ADDR, leadScrewPitch);
    EEPROM.write(EEPROM_DARKMODE_ADDR, darkMode);
    EEPROM.commit();
  }
};

class Button {
private:
  uint8_t pin;
  uint32_t lastPress;
  bool lastState;
public:
  Button(uint8_t p): pin(p), lastPress(0), lastState(true) {
    pinMode(pin, INPUT_PULLUP);
  }
  ButtonEvent read() {
    bool cur = digitalRead(pin);
    uint32_t now = millis();
    ButtonEvent e = ButtonEvent::NONE;
    if(lastState && !cur){
      if(now - lastPress > DEBOUNCE_DELAY){
        e = ButtonEvent::PRESSED;
        lastPress = now;
      }
    }
    lastState = cur;
    return e;
  }
};

volatile int32_t encCount = 0;

void IRAM_ATTR isrA(){
  bool a = digitalRead(ENC_A);
  bool b = digitalRead(ENC_B);
  encCount += (a==b) ? 1 : -1;
}
void IRAM_ATTR isrB(){
  bool a = digitalRead(ENC_A);
  bool b = digitalRead(ENC_B);
  encCount += (a!=b) ? 1 : -1;
}

class DisplayManager {
private:
  Adafruit_ILI9341& tft;
public:
  DisplayManager(Adafruit_ILI9341& d): tft(d) {}
  
  void begin(){
    SPI.begin(TFT_SCK, TFT_MISO, TFT_MOSI, TFT_CS);
    tft.begin();
    tft.setRotation(1);
    tft.fillScreen(C_BG);
  }
  
  void mainMenu(int sel){
    tft.fillScreen(C_BG);

    // Background illustration — left side (193x240, x=0, y=0)
    tft.drawRGBBitmap(BG_MAIN_X, BG_MAIN_Y, bg_main, BG_MAIN_W, BG_MAIN_H);

    // Header: "| MAIN PAGE" — Orbitron 8pt, top-left
    tft.setFont(&Orbitron_Medium8pt7b);
    tft.setTextColor(C_WHITE);
    tft.setCursor(28, 33);
    tft.print("| MAIN PAGE");
    tft.setFont(nullptr);

    // Button-Menu icon — bitmap Off state, top-right (279,16) 24x24
    tft.drawRGBBitmap(BTN_MENU_X, BTN_MENU_Y, btn_menu_off, BTN_MENU_W, BTN_MENU_H);

    // Menu option buttons — right column, Orbitron 8pt
    const char* labels[3] = {"FEED", "THREAD", "DIVIDER"};
    const int btnY[3] = {65, 100, 135};
    const int bx = 210, bw = 110, bh = 25;

    tft.setFont(&Orbitron_Medium8pt7b);
    for(int i = 0; i < 3; i++){
      uint16_t bgColor   = (i == sel) ? C_ACCENT : C_BTN;
      uint16_t textColor = (i == sel) ? C_WHITE  : C_MUTED;
      tft.fillRect(bx, btnY[i], bw, bh, bgColor);
      tft.setTextColor(textColor);

      // Right-align label inside button (Figma: text align = right)
      int16_t x1, y1;
      uint16_t tw, th;
      tft.getTextBounds(labels[i], 0, 0, &x1, &y1, &tw, &th);
      int cx = bx + bw - (int)tw - x1 - 28;  // 28px padding from right edge
      int cy = btnY[i] + (bh - (int)th) / 2 - y1;
      tft.setCursor(cx, cy);
      tft.print(labels[i]);
    }
    tft.setFont(nullptr);
  }

  // Restore a screen rectangle from the bg_main PROGMEM bitmap.
  // Pixels outside the bitmap bounds are filled with C_BG.
  void refreshBgRegion(int x, int y, int w, int h){
    tft.startWrite();
    for(int row = 0; row < h; row++){
      for(int col = 0; col < w; col++){
        int sx = x + col, sy = y + row;
        uint16_t c = C_BG;
        if(sx < BG_MAIN_W && sy < BG_MAIN_H)
          c = pgm_read_word(&bg_main[sy * BG_MAIN_W + sx]);
        tft.writePixel(sx, sy, c);
      }
    }
    tft.endWrite();
  }

  void drawMainRPM(int rpm){
    tft.fillRect(0, 165, 300, 75, C_BG);

    char numBuf[8];
    snprintf(numBuf, sizeof(numBuf), "%d", rpm);
    tft.setFont(&Orbitron_Medium18pt7b);
    tft.setTextColor(C_WHITE);
    tft.setCursor(28, 215);
    tft.print(numBuf);
    tft.setFont(&Orbitron_Medium8pt7b);
    tft.setCursor(tft.getCursorX() + 4, 215);
    tft.print("/ rpm");
    tft.setFont(nullptr);
  }
  
  void configMenu(int sel){
    tft.fillScreen(C_BG);

    // Title — Orbitron 8pt, same position as all screens
    tft.setFont(&Orbitron_Medium8pt7b);
    tft.setTextColor(C_WHITE);
    tft.setCursor(28, 33);
    tft.print("< CONFIGURATION");
    tft.setFont(nullptr);

    // Button-Menu — ON (still inside menu)
    tft.drawRGBBitmap(BTN_MENU_X, BTN_MENU_Y, btn_menu_on, BTN_MENU_W, BTN_MENU_H);

    // Config options — Figma: x=80, w=240, h=25, y=65/100, Orbitron 8pt right-aligned
    const char* items[2] = {"DIRECTION", "LEAD SCREW PITCH"};
    const int OPT_X = 80, OPT_W = 240, OPT_H = 25;
    const int OPT_Y[2] = {65, 100};

    tft.setFont(&Orbitron_Medium8pt7b);
    for(int i = 0; i < 2; i++){
      bool isSel = (i == sel);
      tft.fillRect(OPT_X, OPT_Y[i], OPT_W, OPT_H, isSel ? C_ACCENT : C_BTN);
      tft.setTextColor(isSel ? C_WHITE : C_MUTED);
      int16_t x1, y1; uint16_t tw, th;
      tft.getTextBounds(items[i], 0, 0, &x1, &y1, &tw, &th);
      int textX = OPT_X + OPT_W - 28 - (int)tw - x1;
      int textY = OPT_Y[i] + (OPT_H - (int)th) / 2 - y1;
      tft.setCursor(textX, textY);
      tft.print(items[i]);
    }
    tft.setFont(nullptr);

    // Button-Back — bottom-right
    tft.drawRGBBitmap(262, 182, btn_back_off, BTN_BACK_W, BTN_BACK_H);
  }
  
  void configDirection(bool cwDir){
    tft.fillScreen(C_BG);

    // Title — Orbitron 8pt
    tft.setFont(&Orbitron_Medium8pt7b);
    tft.setTextColor(C_WHITE);
    tft.setCursor(28, 33);
    tft.print("< CONFIG / DIRECTION");
    tft.setFont(nullptr);

    // Button-Menu — ON (inside config hierarchy)
    tft.drawRGBBitmap(BTN_MENU_X, BTN_MENU_Y, btn_menu_on, BTN_MENU_W, BTN_MENU_H);

    // CW / CCW option buttons — Figma: x=68/168, y=85, w=83, h=60
    const char* opts[2] = {"CW", "CCW"};
    const int OPT_X[2] = {68, 168};
    const int OPT_Y = 85, OPT_W = 83, OPT_H = 60;

    tft.setFont(&Orbitron_Medium12pt7b);
    for(int i = 0; i < 2; i++){
      bool isSel = (i == 0) ? cwDir : !cwDir;
      tft.fillRoundRect(OPT_X[i], OPT_Y, OPT_W, OPT_H, 4, isSel ? C_ACCENT : C_BTN);
      tft.setTextColor(isSel ? C_WHITE : C_MUTED);
      int16_t x1, y1; uint16_t tw, th;
      tft.getTextBounds(opts[i], 0, 0, &x1, &y1, &tw, &th);
      int textX = OPT_X[i] + (OPT_W - (int)tw) / 2 - x1;
      int textY = OPT_Y + (OPT_H - (int)th) / 2 - y1;
      tft.setCursor(textX, textY);
      tft.print(opts[i]);
    }
    tft.setFont(nullptr);

    // Buttons — bottom-right (Back=cancel, Ok=save)
    tft.drawRGBBitmap(222, 182, btn_back_off, BTN_BACK_W, BTN_BACK_H);
    tft.drawRGBBitmap(262, 182, btn_ok_off, BTN_OK_W, BTN_OK_H);
  }
  
  void configRatio(uint8_t pitch, int digitSel){
    tft.fillScreen(C_BG);

    // Title — Orbitron 8pt
    tft.setFont(&Orbitron_Medium8pt7b);
    tft.setTextColor(C_WHITE);
    tft.setCursor(28, 33);
    tft.print("< CONF/LEAD SCREW PITCH");
    tft.setFont(nullptr);

    // Button-Menu — ON (inside config hierarchy)
    tft.drawRGBBitmap(BTN_MENU_X, BTN_MENU_Y, btn_menu_on, BTN_MENU_W, BTN_MENU_H);

    // Digit boxes — centered: x=75 (tens) x=165 (units), y=88, w=80, h=65
    // Gap between boxes: 10px — total box area: 170px, startX=(320-170)/2=75
    uint8_t d0 = (pitch / 10) % 10;
    uint8_t d1 = pitch % 10;
    const uint8_t digits[2] = {d0, d1};
    const int OPT_X[2] = {75, 165};
    const int OPT_Y = 88, OPT_W = 80, OPT_H = 65;

    tft.setFont(&Orbitron_Medium24pt7b);
    for(int i = 0; i < 2; i++){
      bool isSel = (i == digitSel);
      tft.fillRoundRect(OPT_X[i], OPT_Y, OPT_W, OPT_H, 4, isSel ? C_ACCENT : C_BTN);
      tft.setTextColor(isSel ? C_WHITE : C_MUTED);
      char buf[2]; snprintf(buf, sizeof(buf), "%d", digits[i]);
      int16_t x1, y1; uint16_t tw, th;
      tft.getTextBounds(buf, 0, 0, &x1, &y1, &tw, &th);
      int textX = OPT_X[i] + (OPT_W - (int)tw) / 2 - x1;
      int textY = OPT_Y + (OPT_H - (int)th) / 2 - y1;
      tft.setCursor(textX, textY);
      tft.print(buf);
    }
    tft.setFont(nullptr);

    // Stepper buttons — centered above/below the active digit box only
    // Up: 8px above box top (y=88-8-30=50), Down: 8px below box bottom (y=88+65+8=161)
    int stepperX = OPT_X[digitSel] + (OPT_W - BTN_STEPPER_W) / 2;
    tft.drawRGBBitmap(stepperX, 50, btn_stepper_up_off, BTN_STEPPER_W, BTN_STEPPER_H);
    tft.drawRGBBitmap(stepperX, 161, btn_stepper_down_off, BTN_STEPPER_W, BTN_STEPPER_H);

    // Buttons — bottom-right (Back=cancel, Ok=confirm digit / save)
    tft.drawRGBBitmap(222, 182, btn_back_off, BTN_BACK_W, BTN_BACK_H);
    tft.drawRGBBitmap(262, 182, btn_ok_off, BTN_OK_W, BTN_OK_H);
  }
  
  void drawAvanceSelect(int sel){
    tft.fillScreen(C_BG);

    // Header: "< FEED SELECTION" — Orbitron 8pt, top-left
    tft.setFont(&Orbitron_Medium8pt7b);
    tft.setTextColor(C_WHITE);
    tft.setCursor(28, 33);
    tft.print("< FEED SELECTION");
    tft.setFont(nullptr);

    // Button-Menu icon — top-right (same position as main screen)
    tft.drawRGBBitmap(BTN_MENU_X, BTN_MENU_Y, btn_menu_off, BTN_MENU_W, BTN_MENU_H);

    // Feed option grid — 2 cols x 3 rows (6 slots, 5 with values)
    // Figma: tab w=110 h=20, col_left x=40, col_right x=170, rows y=65/100/135
    const int COLS = 2;
    const int ROWS = 3;
    const int TAB_W = 110, TAB_H = 20;
    const int TAB_GAP_X = 20, TAB_GAP_Y = 15;
    const int GRID_X = 40, GRID_Y = 65;

    // Tab text: Figma=10px → Orbitron 8pt (Adafruit fonts render ~30% taller than stated)
    tft.setFont(&Orbitron_Medium8pt7b);
    for(int i = 0; i < COLS * ROWS; i++){
      int col = i % COLS;
      int row = i / COLS;
      int x = GRID_X + col * (TAB_W + TAB_GAP_X);
      int y = GRID_Y + row * (TAB_H + TAB_GAP_Y);

      if(i < NUM_AV){
        bool isSel = (i == sel);
        uint16_t bgColor = isSel ? C_ACCENT : C_BTN;
        uint16_t txColor = isSel ? C_WHITE  : C_MUTED;
        tft.fillRect(x, y, TAB_W, TAB_H, bgColor);
        tft.setTextColor(txColor);
        char buf[8];
        snprintf(buf, sizeof(buf), "%.2f", avances[i]);
        int16_t x1, y1; uint16_t tw, th;
        tft.getTextBounds(buf, 0, 0, &x1, &y1, &tw, &th);
        tft.setCursor(x + (TAB_W - (int)tw) / 2 - x1,
                      y + (TAB_H - (int)th) / 2 - y1);
        tft.print(buf);
      }
      // 6th slot: empty (C_BG background)
    }
    tft.setFont(nullptr);

    // Pagination bar — bottom-left
    // Figma: caret_left x=29 y=192, text x=44, caret_right x=77
    const int PAGE_SLOTS = COLS * ROWS;
    const int totalPages = (NUM_AV + PAGE_SLOTS - 1) / PAGE_SLOTS;
    // Solid caret-left (mirrored) — off on page 1 (no previous page)
    tft.drawRGBBitmap(17, 182, solid_left_off, SOLID_W, SOLID_H);
    // "1 / N" label — Figma=10px → Orbitron 8pt
    tft.setFont(&Orbitron_Medium8pt7b);
    tft.setTextColor(C_WHITE);
    char pagBuf[8];
    snprintf(pagBuf, sizeof(pagBuf), "1 / %d", totalPages);
    tft.setCursor(44, 199);
    tft.print(pagBuf);
    int afterPag = tft.getCursorX();
    tft.setFont(nullptr);
    // Solid caret-right — off when only 1 page
    tft.drawRGBBitmap(afterPag + 4, 182, solid_off, SOLID_W, SOLID_H);

    // Button-Back and Button-Ok — bottom-right (Figma: x=222/262, y=182)
    tft.drawRGBBitmap(222, 182, btn_back_off, BTN_BACK_W, BTN_BACK_H);
    tft.drawRGBBitmap(262, 182, btn_ok_off, BTN_OK_W, BTN_OK_H);
  }
  
  void drawThreadUnitSwitch(int sel){
    // sel: 0=METRIC, 1=UTS
    tft.fillScreen(C_BG);
    tft.setFont(&Orbitron_Medium8pt7b);
    tft.setTextColor(C_WHITE);
    tft.setCursor(28, 33);
    tft.print("< THREADS UNIT SWITCH");
    tft.setFont(nullptr);
    tft.drawRGBBitmap(BTN_MENU_X, BTN_MENU_Y, btn_menu_off, BTN_MENU_W, BTN_MENU_H);

    const char* labels[] = {"METRIC", "UTS"};
    const int OPT_Y[]    = {72, 117};
    tft.setFont(&Orbitron_Medium8pt7b);
    for(int i = 0; i < 2; i++){
      uint16_t bg = (sel == i) ? C_ACCENT : C_BTN;
      uint16_t fg = (sel == i) ? C_WHITE  : C_MUTED;
      tft.fillRoundRect(28, OPT_Y[i], 264, 30, 4, bg);
      tft.setTextColor(fg);
      int16_t x1, y1; uint16_t tw, th;
      tft.getTextBounds(labels[i], 0, 0, &x1, &y1, &tw, &th);
      tft.setCursor(28 + (264 - (int)tw) / 2 - x1, OPT_Y[i] + (30 + (int)th) / 2);
      tft.print(labels[i]);
    }
    tft.setFont(nullptr);
    tft.drawRGBBitmap(222, 182, btn_back_off, BTN_BACK_W, BTN_BACK_H);
    tft.drawRGBBitmap(262, 182, btn_ok_off,   BTN_OK_W,   BTN_OK_H);
  }

  // Generic thread selection page — handles any number of items and pages
  // page: 0-indexed page number | sel: absolute index in array | imperial: unit mode
  void drawRoscaPage(int page, int sel, bool imperial){
    tft.fillScreen(C_BG);
    tft.setFont(&Orbitron_Medium8pt7b);
    tft.setTextColor(C_WHITE);
    tft.setCursor(28, 33);
    tft.print(imperial ? "< THREAD SELECTION (tpi)" : "< THREAD SELECTION (mm)");
    tft.setFont(nullptr);
    tft.drawRGBBitmap(BTN_MENU_X, BTN_MENU_Y, btn_menu_off, BTN_MENU_W, BTN_MENU_H);

    const int tot         = imperial ? NUM_ROS_IMP : NUM_ROS;
    const int total_pages = (tot + ROSCA_PAGE_SIZE - 1) / ROSCA_PAGE_SIZE;
    const int start       = page * ROSCA_PAGE_SIZE;
    const int count       = min(ROSCA_PAGE_SIZE, tot - start);

    // Grid: 2×4 layout (8 items per page)
    const int COLS = 2;
    const int TAB_W = 110, TAB_H = 20, TAB_GAP_X = 20, TAB_GAP_Y = 15;
    const int GRID_X = 40, GRID_Y = 65;

    tft.setFont(&Orbitron_Medium8pt7b);
    for(int i = 0; i < count; i++){
      int idx = start + i;
      int col = i % COLS, row = i / COLS;
      int x = GRID_X + col * (TAB_W + TAB_GAP_X);
      int y = GRID_Y + row * (TAB_H + TAB_GAP_Y);
      bool isSel = (idx == sel);
      tft.fillRect(x, y, TAB_W, TAB_H, isSel ? C_ACCENT : C_BTN);
      tft.setTextColor(isSel ? C_WHITE : C_MUTED);
      char buf[12];
      if(imperial){
        float t = tpi_vals[idx];
        if(t == (float)(int)t) snprintf(buf, sizeof(buf), "%d", (int)t);
        else                   snprintf(buf, sizeof(buf), "%.1f", t);
      } else {
        snprintf(buf, sizeof(buf), "%.2f", roscas[idx]);
      }
      int16_t x1, y1; uint16_t tw, th;
      tft.getTextBounds(buf, 0, 0, &x1, &y1, &tw, &th);
      tft.setCursor(x + (TAB_W - (int)tw) / 2 - x1, y + (TAB_H - (int)th) / 2 - y1);
      tft.print(buf);
    }
    tft.setFont(nullptr);

    // Pagination — carets reflect available prev/next pages
    bool hasLeft  = (page > 0);
    bool hasRight = (page < total_pages - 1);
    tft.drawRGBBitmap(17, 182, hasLeft ? solid_left_on : solid_left_off, SOLID_W, SOLID_H);
    tft.setFont(&Orbitron_Medium8pt7b);
    tft.setTextColor(C_WHITE);
    tft.setCursor(44, 199);
    char pag[8]; snprintf(pag, sizeof(pag), "%d / %d", page + 1, total_pages);
    tft.print(pag);
    int afterPag = tft.getCursorX();
    tft.setFont(nullptr);
    tft.drawRGBBitmap(afterPag + 4, 182, hasRight ? solid_on : solid_off, SOLID_W, SOLID_H);

    tft.drawRGBBitmap(222, 182, btn_back_off, BTN_BACK_W, BTN_BACK_H);
    tft.drawRGBBitmap(262, 182, btn_ok_off,   BTN_OK_W,   BTN_OK_H);
  }
  
  void modeScreen(const char* title, float value, const char* unit){
    tft.fillScreen(C_BG);

    // Title — Orbitron 8pt, white, top-left (same position as all screens)
    tft.setFont(&Orbitron_Medium8pt7b);
    tft.setTextColor(C_WHITE);
    tft.setCursor(28, 33);
    tft.print(title);
    tft.setFont(nullptr);

    // Button-Menu — top-right (same position as all screens)
    tft.drawRGBBitmap(BTN_MENU_X, BTN_MENU_Y, btn_menu_off, BTN_MENU_W, BTN_MENU_H);

    // Value panel — Figma: x=30, y=81, w=260, h=60, rounded 6px, C_ACCENT bg
    const int PANEL_X = 30, PANEL_Y = 81, PANEL_W = 260, PANEL_H = 60;
    tft.fillRoundRect(PANEL_X, PANEL_Y, PANEL_W, PANEL_H, 6, C_ACCENT);

    // Measure number string (25pt) and unit string (9pt) to center together
    char numBuf[12];
    snprintf(numBuf, sizeof(numBuf), "%.2f", value);
    char unitBuf[12];
    snprintf(unitBuf, sizeof(unitBuf), "/ %s", unit);

    // Figma: number 40px → 24pt; unit 12px → 8pt (Adafruit renders larger than stated for big pt)
    tft.setFont(&Orbitron_Medium24pt7b);
    int16_t nx, ny; uint16_t nw, nh;
    tft.getTextBounds(numBuf, 0, 0, &nx, &ny, &nw, &nh);

    tft.setFont(&Orbitron_Medium8pt7b);
    int16_t ux, uy; uint16_t uw, uh;
    tft.getTextBounds(unitBuf, 0, 0, &ux, &uy, &uw, &uh);

    // Horizontal: center combined text in panel (6px gap between number and unit)
    const int GAP = 6;
    int totalW = (int)(nw - nx) + GAP + (int)(uw - ux);
    int startX  = PANEL_X + (PANEL_W - totalW) / 2;

    // Vertical: center number glyph in panel
    int panelCenterY = PANEL_Y + PANEL_H / 2;
    int baselineY    = panelCenterY - ny - (int)nh / 2;

    // Draw number in 24pt
    tft.setFont(&Orbitron_Medium24pt7b);
    tft.setTextColor(C_WHITE);
    tft.setCursor(startX - nx, baselineY);
    tft.print(numBuf);

    // Draw unit in 8pt on same baseline
    tft.setFont(&Orbitron_Medium8pt7b);
    tft.setCursor(tft.getCursorX() + GAP, baselineY);
    tft.print(unitBuf);
    tft.setFont(nullptr);

    // Button-Back — bottom-right (no Button-Ok in mode screens)
    tft.drawRGBBitmap(262, 182, btn_back_off, BTN_BACK_W, BTN_BACK_H);
  }
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
void loop(){
  app.run();
}

// ===== Core1: dedicated FreeRTOS servo task (ESP32) =====
void servoTask(void* pvParameters) {
  servoLastE_c1 = encCount;  // Sync initial position
  for (;;) {
    updateServoCore1();
    vTaskDelay(1);  // Yield to the scheduler — avoids WDT and lets Core1 service other tasks
  }
}

void setup(){
  Serial.begin(115200);
  app.begin();
  // Launch the servo task on Core1 with high priority (24) and a 2KB stack
  xTaskCreatePinnedToCore(
    servoTask,    // task function
    "ServoTask",  // name (debug)
    4096,         // stack in bytes (float + PROGMEM arrays need enough stack)
    nullptr,      // parameter
    24,           // priority (0=min, 25=max on ESP32)
    nullptr,      // handle (not needed)
    1             // Core1
  );
}

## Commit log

2026-01-28 ESp32 Torno V1
2026-02-28 Rename project folder to esp32-lathe, add all project files
    - Rename 'ESp32 Torno/' -> 'esp32-lathe/' (removes spaces from path)
    - Add .gitignore (excludes assets, tokens, internal docs)
    - Add .vscode/ IntelliSense config for ESP32 C/C++
    - Add .claude/ Claude Code permission settings
    - Add Fonts/ (Orbitron + Montserrat bitmap fonts)
    - Add PROGMEM bitmap headers (buttons, icons, logo, background)
    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
2026-02-28 Migrate project structure for real hardware (Arduino IDE 2.x)
    - Rename sketch.ino -> esp32-lathe.ino (Arduino IDE requires .ino name to match folder)
    - Move 9 bitmap headers into bitmaps/ subfolder
    - Update all #include paths: bitmaps/* and Fonts/*
    - Remove Wokwi-specific files (diagram.json, libraries.txt)
2026-02-28 Remove #pragma once and pgmspace.h from bitmap headers
    Both are forbidden in ESP32 bitmap files — the Arduino core provides
    PROGMEM support automatically and these headers break IntelliSense.
2026-03-08 Add Thread Unit Switch screen and imperial thread support
    - New THREAD_UNIT_SWITCH state: selects Metric or Imperial before thread selection
    - Replaced ROSCA_SELECT_P1/P2 with generic ROSCA_SELECT + drawRoscaPage(page, sel, imperial)
    - Metric array extended to 16 pitches (0.20–4.00 mm); imperial array 21 TPI values (8–56)
    - Servo Core1 uses roscas_imperial[] when g_imperialThread is true
    - drawThreadUnitSwitch() uses btn_menu_off (operational screen, not menu hierarchy)
    - Thread Mode display shows TPI value for imperial, pitch (mm) for metric
    [esp32-lathe.ino]
2026-03-23 Rename IMPERIAL to UTS in Thread Unit Switch screen
2026-07-07 Enable XPT2046 touch for real hardware and translate comments to English
    - Re-enable XPT2046 touchscreen (library, touch.begin(), calibration constants)
    - Rewrite handleTouch() with Figma redesign touch zones + hitRect() helper
    - Add TOUCH_DEBOUNCE (250ms) and lastTouchTime tracking
    - Remove legacy dead code: hud(), drawRPM(), drawBack(), drawGearIcon() and unused grid constants
    - Translate all inline comments from Spanish to English (per project guideline)
    - Add user manuals and component list under Resources/
    [esp32-lathe.ino]
2026-07-07 Update README: touchscreen input and Resources manuals
    - Document XPT2046 touchscreen as an active input method (features, hardware
    table, pin map) alongside the physical buttons
    - Clarify Metric/Imperial (UTS) thread selection via Thread Unit Switch
    - Add Resources/ folder to the project structure tree
    - Add Documentation section linking the English and Spanish user manuals and
    the component list
2026-07-09 Add 3D part models and update component list PDF
    - Update ELS_Componentes.pdf with the correct links to the referenced parts
    - Add Resources/Components/ with the mechanical 3D models (STEP + STL)
    - Document the 3D models and the updated BOM in the README
    [Axis.STEP, Base.STEP, Encoder support.STEP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]
2026-07-13 Add Buy Me a Coffee funding link
    - Add .github/FUNDING.yml so GitHub shows a Sponsor button at the top of the repo
    - Feature the Buy Me a Coffee badge and callout prominently in the README
2026-07-14 Add circuit schematic PDF
    - Add Resources/Schematic.pdf (circuit schematic)
    - Reference it in the README documentation table and project tree
2026-07-20 Add servo driver affiliate link and Where to Buy section
2026-07-21 Update servo driver affiliate link and add recommended model reference

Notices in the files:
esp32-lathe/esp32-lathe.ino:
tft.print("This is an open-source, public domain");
